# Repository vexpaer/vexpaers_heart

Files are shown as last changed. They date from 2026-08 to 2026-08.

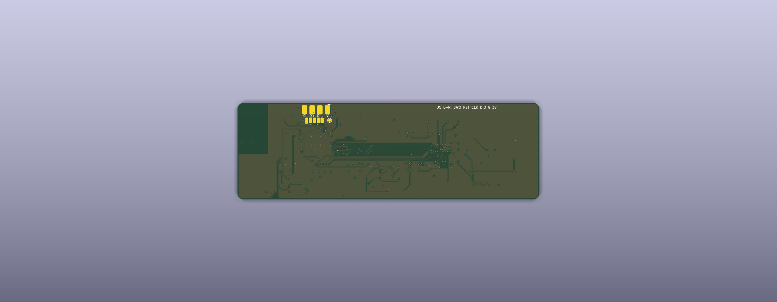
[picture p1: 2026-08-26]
hardware/heart_v2/docs/heart_v2_final_bottom_3d.png

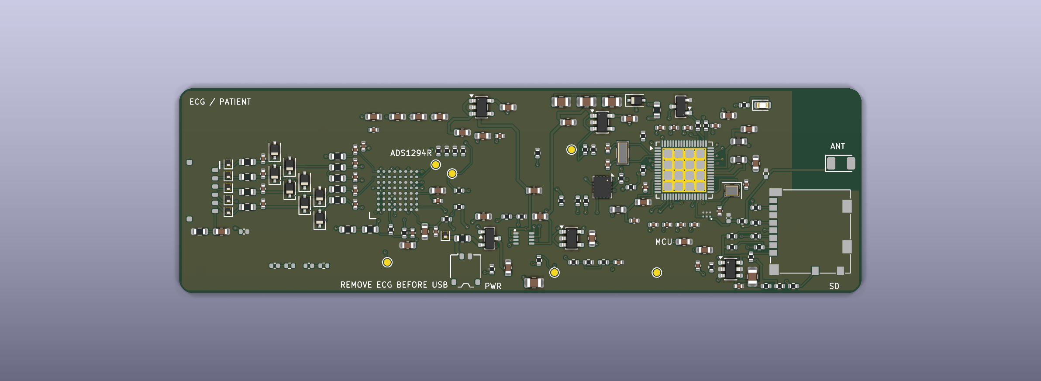
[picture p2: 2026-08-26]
hardware/heart_v2/docs/heart_v2_current_top_3d_close.png

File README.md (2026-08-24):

# vexpaer's heart — clean PCB rebuild

This branch resets the PCB layout workflow without losing the previous design.

- `Old/`: complete archived V1 design and production outputs.
- `reference/`: only the electrical/spec/library files needed for the rebuild.
- `hardware/heart_v2/`: clean workspace for the new PCB.
- `PCB_WORKFLOW.md`: the one document Codex should follow from setup to final manufacturing outputs.

The new PCB must be placement-first and human-routed. Do not use the archived PCB tracks or a global autorouter as the final layout.

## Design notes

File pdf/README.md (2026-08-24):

# PDF 审阅索引

这里的 PDF 由最终签核的 KiCad 文件生成，方便在不安装 KiCad 的设备上审阅。

- `holter_v1_schematic.pdf`：主板完整原理图；
- `holter_v1_pcb_layers.pdf`：主板四个铜层，每层一页并叠加板框；
- `holter_v1_assembly_top.pdf`：主板顶层装配图；
- `holter_v1_assembly_bottom.pdf`：主板底层装配图（已镜像为装配视角）；
- `usb_pogo_dock_schematic.pdf`：USB-Pogo 底座原理图；
- `usb_pogo_dock_pcb_layers.pdf`：底座两层铜层；
- `usb_pogo_dock_assembly_top.pdf`：底座顶层装配图；
- `usb_pogo_dock_assembly_bottom.pdf`：底座底层装配图。

PDF 用于人工审阅，不替代 `production/` 中的 Gerber、钻孔文件和签核报告。

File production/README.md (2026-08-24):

# 制造资料与下单说明

每个板卡子目录均包含 Gerber/Excellon、BOM、贴片坐标、钻孔报告、ERC/DRC
报告，以及可直接上传 PCB 厂商的 fabrication ZIP。厂商应以 Gerber 和钻孔文件
为制造依据；KiCad/PDF 用于工程复核。

## Holter 主板下单参数

- 首批数量：5；成品尺寸：100.0 mm × 30.0 mm；板厚：0.8 mm；
- 4 层：L1 元件/信号、L2 完整 GND、L3 电源/信号、L4 信号；
- 铜厚：各层 1 oz；表面处理：ENIG、无铅；
- 最小线宽/间距：0.10/0.10 mm；最小成品孔：0.20 mm；
- 全部 253 个过孔均为 0.45/0.20 mm 普通电镀通孔；没有盲孔、埋孔、
  微孔、盘中孔、填孔或盖孔要求；
- 阻焊覆盖普通过孔；颜色可选，但不得覆盖 J3/J5 的底层 Pogo/SWD ENIG
  接触面；
- 主要元器件仅顶层 SMT。J3、J5 是底层裸露接触焊盘，不是待贴装器件；
- DNP：C10、C26、C27、C65、C66、R18、R19；首板不要安装这些位置；
- 天线区域四层禁铺铜、禁放过孔；不得删除或缩小板文件中的 keepout。

### RF 与阻抗 EQ

RF 走线在顶层、宽 0.18 mm，参考 L2 GND。该线宽只有结合实际介质厚度与
介电常数后才可能构成 50 Ω。下单时要求厂商：

1. 按其 0.8 mm 四层量产层叠计算并确认顶层 0.18 mm 单端线的阻抗；
2. 目标 50 Ω，建议容差 ±10%；
3. 如果标准层叠无法满足，必须暂停 EQ 并反馈可用层叠/线宽，不得自行改线宽、
   板厚或天线 keepout 后直接生产。

RF π 网络的 C65/C66 首板保持 DNP、R51 安装 0 Ω。最终值只能在整机外壳、电池
和人体邻近条件下做 VNA 测量后冻结。

### USB 与 microSD 限制

- USB 仅按 USB 2.0 Full-Speed 12 Mbit/s 使用，不支持 High-Speed；当前走线不是
  紧密耦合的 90 Ω 差分对。首板必须做枚举、持续传输和供电切换测试；
- microSD 首板固件先用 4 MHz SPI 初始化和压力测试，通过后再提高；初始建议
  上限 12 MHz；
- 不得因厂商 EQ 任意更换 0.8 mm 层叠、改变 RF/USB 走线或移动器件。

## USB-Pogo 底座下单参数

- 首批数量：5；成品尺寸：42.0 mm × 24.0 mm；
- 2 层、1.6 mm、1 oz、ENIG、无铅；
- USB-C、ESD/保护器件和指示灯按 BOM/CPL 贴装；
- Pogo 弹簧针与机械定位件由夹具结构决定，按装配图手工安装；
- 与主板接触顺序固定为 `VBUS / D- / D+ / GND`，不得镜像或调换。

## 安全标识与首板验证

主板和夹具上的 `DISCONNECT ELECTRODES BEFORE USB` / 互锁提示不得删除。
本设计没有患者侧 USB 隔离，连接人体电极时严禁连接 USB/Pogo；USB 导出或刷机
前必须先拔下整条电极线缆。

这是一套研究原型，不是医疗器械。任何人体连接之前，必须先在 ECG 模拟器和
患者等效假负载上验证输入漏电/偏置、RLD 稳定性、噪声、ESD 恢复和故障状态；
同时完成 RF、USB、microSD、电源温升、反向电流、电池极性及机械互锁验证。

详细证据和仍需实测的项目见 `docs/HARDWARE_AUDIT.md`。

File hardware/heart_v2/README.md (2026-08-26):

# heart_v2

Heart V2 Rev A is a clean, from-schematic PCB rebuild for the Holter research
prototype.  The layout is frozen as a four-layer, 0.8 mm, 100 mm x 32 mm board.
The extra 2 mm is a user-authorized service strip for separate bottom-side USB
and SWD pogo rows.

The placement and routing are deliberately scripted and reproducible.  They do
not read an archived PCB, reuse `Old/` copper, invoke Freerouting, or call a
global autorouter.

## Release status

- ERC: 0 errors, 0 warnings
- DRC: 0 violations, 0 unconnected pads, 0 footprint errors
- Schematic/PCB electrical parity: clean
- Fabrication, assembly and review outputs: `production/`
- Layout audit and first-board checks: `docs/AUDIT.md`

This is a research prototype, not a medical device.  It has no patient-side USB
isolation or defibrillation protection.  Disconnect every electrode before
connecting USB, exactly as the board silkscreen states.

## Source and regeneration

- `heart_v2.kicad_sch`, `heart_v2.kicad_pcb`, `heart_v2.kicad_pro`: KiCad 10 source
- `scripts/place_components.py`: deterministic functional placement and outline
- `scripts/route_board.py`: deterministic human-style routing, zones and stitching
- `scripts/export_release.sh`: final checks and manufacturing export
- `libraries/`: project symbols and footprints

Run the placement and routing scripts with a Python environment that provides
KiCad 10 `pcbnew`, then run the release exporter:

```bash
python3 scripts/place_components.py
python3 scripts/route_board.py
bash scripts/export_release.sh
```

Do not regenerate this board from `Old/`; that directory remains archival only.

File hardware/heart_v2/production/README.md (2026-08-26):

# Heart V2 Rev A production package

Fabrication target: four layers, 0.8 mm, 100 x 32 mm, ENIG.  Confirm the exact
0.8 mm stackup and the 0.24 mm 50-ohm RF geometry with the selected board house
before ordering.

## Files

- `heart_v2_fab_revA.zip`: Gerber X2/job, PTH/NPTH drill and IPC-D-356 data.
- `heart_v2_release_revA.zip`: complete source, checks, fabrication and assembly
  deliverables.
- `heart_v2_bom.csv`: assembly BOM with DNP parts excluded.
- `heart_v2_bom_all.csv`: engineering BOM including DNP parts.
- `heart_v2_cpl.csv`: both-side metric placement file, DNP excluded.
- `docs/heart_v2_assembly_top.pdf`: 1:1 top assembly drawing.
- `docs/heart_v2_assembly_bottom.pdf`: 1:1 mirrored bottom assembly drawing.
- `docs/heart_v2_copper_layers.pdf`: four-page 1:1 copper review drawing.
- `docs/heart_v2_schematic.pdf`: schematic review PDF.
- `../docs/jlcpcb_pcba_order_guide.html`: detailed Chinese JLCPCB PCB+SMT ordering
  and first-board bring-up guide (open locally in a browser).

Gerber, drill and CPL outputs share the physical lower-left board corner as
their origin.  CPL positions are all positive.  Verify bottom-side rotation and
the rendered placement preview in the assembler portal before approval.

J3/J5 USB/SWD pogo contacts and TP1-TP6 test pads are bare board-contact/test
structures, not SMT parts, so they are intentionally omitted from the BOM/CPL
matching list.  The assembled board still contains their copper pads.

The board is a non-isolated research prototype.  Disconnect electrodes before
USB, and validate with an ECG simulator/patient-equivalent load before any human
connection.

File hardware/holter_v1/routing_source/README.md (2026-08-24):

# Routing source

`holter_v1-freerouted-input.kicad_pcb` is the frozen Freerouting intermediate
used by `tools/finish_main_routes.py`. It is committed only to make the final
manual routing stage reproducible.

Do **not** send this intermediate board to a manufacturer. It does not contain
the final PA10 microSD-CS/SD-clock completion and its imported layer-changing
drills may still be labelled as buried vias. The signed-off fabrication source
is `../holter_v1.kicad_pcb`; the finishing script converts every final drill to
a 0.45/0.20 mm ordinary plated through-via before saving.

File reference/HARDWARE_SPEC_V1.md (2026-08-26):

# Holter V1 Hardware Specification

**项目名称**：Holter V1<br>
**用途**：研究/个人工程原型；连续 ECG + 运动数据记录<br>
**硬件 CAD**：KiCad<br>
**目标生产方式**：PCB 打样 + SMT 贴片，拿到板后通过 SWD/USB 烧录固件<br>
**版本**：V1.0<br>
**状态**：规格冻结；Heart V2 Rev A 制造发布候选已完成 ERC/DRC 签核（2026-08-26）

> 2026-08-23 实施修订：原规格中的 `STM32WB55CGU6 / UFQFPN48` 无法同时提供两组完整、独立的 SPI 引脚。V1 已改为 `STM32WB55RGV6 / VFQFPN68`，ADS1294R 使用 SPI1，microSD 使用 SPI2。本修订属于修复引脚资源冲突，不改变 1 MB Flash、BLE 或 USB FS 功能目标。

> 2026-08-26 机械实施修订：经用户授权，最终 PCB 在原 100 × 30 mm 上限基础上仅向北侧增加 2 mm 服务触点带，成品外形为 **100 × 32 mm**。新增面积用于分离 USB/SWD Pogo 排，不改变 ECG、microSD 或天线端的功能分区；外壳和夹具以最终板框为准。

---

## 1. V1 核心目标

设计一块可放入薄型金属盒中的低功耗可穿戴 ECG 记录主板：

- PCB 最终外形：**32 mm × 100 mm**（含 2 mm 服务触点带）
- PCB 建议厚度：**0.8 mm，4 层**
- 主板总高度目标：**≤ 3 mm**（不计外部电池、导联线、电极）
- 外壳内部高度目标：约 **5 mm**
- 尽量采用**单面贴装**：所有主要器件放在 PCB 同一面，背面尽量只保留测试点、Pogo 接触区和必要铜面
- 5 个体表电极，一根总线从设备引出后分成 5 根电极线
- 连续记录 ECG 和 IMU
- 本地 microSD 存储
- BLE 用于配置、状态、时间同步和短时实时预览
- USB 2.0 Full-Speed 通过 4 个 Pogo 触点进行数据导出和正常固件升级
- 电池可手动更换，主板**不包含充电电路**

> 本项目是研究/工程原型，不作为医疗诊断设备使用。

---

## 2. 已冻结的核心器件

### 2.1 ECG AFE

**TI ADS1294R**

要求：

- 4 通道
- 24-bit 同步 ADC
- SPI 接口
- 默认采样率：**500 SPS**
- CH1~CH3 用于 ECG
- CH4 预留为备用生物电通道
- 使用 ADS1294R 内置：
  - RLD（Right Leg Drive）
  - Lead-off detection
  - Wilson Central Terminal（WCT）
  - 内部参考/时钟方案按 TI datasheet 与官方参考设计实现
- V1 暂不要求启用呼吸阻抗功能，但不得破坏以后启用的可能性

封装优先：
- **NFBGA 8 mm × 8 mm**，以降低面积和高度
- 如果 SMT 厂 BGA 能力/成本不合适，再评估其他可采购封装；任何封装变更必须记录在设计说明中

### 2.2 主控 MCU

**ST STM32WB55RGV6**

要求：

- VFQFPN68，约 **8 × 8 × 1 mm**
- BLE
- USB 2.0 Full-Speed Device
- 1 MB Flash
- MCU 同时负责：
  - ADS1294R SPI 采集
  - microSD SPI 写入
  - IMU 采集
  - BLE
  - USB 数据导出
  - RTC/时间管理
  - 电池电压检测
  - Lead-off 状态处理
- 固定总线分配：
  - SPI1：ADS1294R（PA5/PA6/PA7，PA4 片选）
  - SPI2：microSD（PB13/PB14/PB15；PA10 作为软件控制片选）
  - I²C1：BMI270（PB8/PB9）

### 2.3 IMU

**Bosch BMI270**

要求：

- 6 轴 IMU：3 轴加速度 + 3 轴陀螺仪
- I²C 或 SPI；V1 优先 I²C，以节省 SPI 片选和布线复杂度
- 默认记录频率：**50 Hz**
- 后续固件允许降到 25 Hz
- 用途：活动、姿态变化、运动伪迹辅助判断

### 2.4 存储

**32 GB microSD / microSDHC**

要求：

- **只使用 microSD，不预留 SPI NAND**
- MCU 通过 **SPI 模式**访问 microSD
- 采用超薄、水平侧插卡座
- microSD 与 PCB **平行**
- 卡从外壳侧面/端部沿 PCB 平面滑入
- 卡座总高度优先 **≤ 1.5 mm**
- 优先 push-push 或可靠 push-pull 结构
- 卡槽建议布置在 PCB 的一个短边，外壳对应位置开 microSD 插入口
- 插卡状态检测如卡座支持则接入 MCU

建议文件系统：
- 32 GB：FAT32
- 固件必须使用顺序追加写入，避免大量随机写
- 建议使用 RAM buffer 后按较大 block 写入 microSD，降低功耗和掉电损坏风险

---

## 3. 电极与 ECG 通道定义

### 3.1 五电极

一根总导联线从主机引出，再分成：

1. **RA**
2. **LA**
3. **LL**
4. **RL**
5. **V5**

长期佩戴时可使用躯干化的 Holter 电极布置，而不是四肢末端位置。

建议人体位置：

- RA：右上胸
- LA：左上胸
- LL：左下胸/左下躯干
- RL：右下胸/右下躯干
- V5：左侧 V5 区域（与 V4 同水平、接近左前腋线）

注意：这种长期佩戴布置属于 Holter/监护式躯干电极布置，所得肢体导联形态不能假定与标准静息 12 导联四肢末端放置完全一致。

### 3.2 采集通道

目标：

- **CH1：Lead I = LA - RA**
- **CH2：Lead II = LL - RA**
- **CH3：V5 - WCT**
- **CH4：备用**

其中：

- WCT 由 RA、LA、LL 形成 Wilson Central Terminal
- CH3 必须依据 ADS1294R 的 WCT 推荐电路/寄存器实现，不要把 V5 简单接成 V5-RA

软件可由 CH1、CH2 计算：

- Lead III = Lead II - Lead I
- aVR = -(Lead I + Lead II) / 2
- aVL = Lead I - Lead II / 2
- aVF = Lead II - Lead I / 2

因此 V1 可输出：

- I
- II
- III
- aVR
- aVL
- aVF
- V5

其中前 6 个肢体方向只有 2 个独立自由度；V5 是额外真实胸导联信息。

---

## 4. ECG 输入与人体安全要求

这一部分优先级高于尺寸和 BOM 成本。

### 4.1 原则

- 输入保护、RLD、RC/EMI 网络优先参考 TI ADS129x 官方 ECG 参考设计和 datasheet
- 禁止由 Agent 自行“猜”患者输入保护电路
- 输入保护器件必须关注：
  - 漏电流
  - 输入偏置影响
  - ESD
  - RF/EMI
  - 限流
  - 电极断开状态
- 输入走线尽可能短、对称，远离：
  - USB
  - microSD 时钟
  - MCU 高频时钟
  - BLE RF
  - DC/DC 开关节点

### 4.2 USB 使用安全

**佩戴电极时，不允许连接电脑 USB/Pogo。**

V1 没有医疗级 USB 隔离，因此：

- USB 数据导出/刷机前先拔掉 5 电极导联总线
- Pogo VBUS 不得给锂电池充电
- USB 供电路径与电池路径需要避免反灌
- PCB 上明确丝印/说明：
  - `DISCONNECT ELECTRODES BEFORE USB`

### 4.3 RLD

- RL 电极作为 RLD/偏置驱动电极使用
- RLD 回路必须按照 ADS1294R datasheet 与官方 ECG 参考设计实现
- RLD 稳定性网络必须计算并在原理图中标注设计依据

---

## 5. 电源架构

### 5.1 电池

- 单节 **3.7 V 1000 mAh LiPo**
- 可拆卸
- 用户准备两块电池轮换
- 目标换电周期：约每 **12 小时**
- 主板**不集成充电器**

要求使用带自身保护的电池包，主板额外提供：

- 反接/反灌保护
- 过流保护或合适的保险/限流方案
- 欠压检测
- 电池电压 ADC 采样

### 5.2 电池连接器

- 2-pin
- 低高度
- 侧插
- 带防呆/锁定优先
- 高度目标 ≤ 2 mm 左右
- 最终型号根据 SMT 厂可采购库存决定，但不得使用明显超过 3 mm 的高连接器

### 5.3 电源轨

设计目标：

- 模拟和数字区域分区供电、布局隔离
- 不为了省一个 LDO 而让 microSD/MCU 的数字噪声直接污染 ECG AFE
- 优先评估：
  - `3.0 V_A`：ADS1294R 模拟
  - `3.0 V_D`：STM32WB / ADS1294R DVDD / IMU / microSD
  - `3.3 V_USB`：仅由 USB VBUS 产生，专供 STM32 VDDUSB
- 低噪声 LDO 优先
- 如果必须使用开关电源，开关节点必须远离 AFE，并经过低噪声后级处理；V1 尽量避免不必要的 DC/DC

电池最低工作电压、LDO dropout、STM32 USB VDDUSB 要结合 datasheet 重新核算后冻结。

---

## 6. 换电与 RTC

V1 允许换电时产生几秒钟 ECG 中断，不做真正的无缝热插拔。

要求：

- STM32 RTC 用于绝对时间
- 增加低高度 RTC/backup hold-up 电容
- 目标：拔电池后至少保持 RTC/关键状态 **≥ 60 秒**
- 换电后：
  - 自动重新初始化 ADS1294R、IMU、microSD
  - 建立新 recording segment
  - 在日志中写入 battery swap / reboot 事件
- 如果 RTC hold-up 失效：
  - BLE 或 USB 重新同步时间
  - 禁止悄悄生成错误绝对时间

---

## 7. BLE

用途限定为：

- 配置
- 时间同步
- 电池状态
- microSD 容量
- 电极 lead-off 状态
- 开始/停止记录
- 短时间实时 ECG 预览
- 固件状态/版本信息

BLE **不作为每天数百 MB 数据的主要导出通道**。

### 金属外壳注意

铁盒会显著衰减 2.4 GHz BLE。

PCB 必须：

- 给天线留完整 RF keepout
- 天线尽量位于 PCB 边缘
- 天线位置对应外壳塑料窗口/开口，或接受“开盖后使用 BLE”
- 不允许把 PCB 天线完全压在连续金属盒壁下仍假定 BLE 正常

V1 建议预留匹配网络，使用低高度 2.4 GHz 芯片天线或经验证的 PCB 天线方案。

---

## 8. USB + Pogo 数据接口

### 8.1 外露触点

主机不安装 USB-C 母座。

PCB 上留 4 个镀金平面触点：

1. VBUS
2. D-
3. D+
4. GND

由外部 Pogo Pin 底座连接：

`Holter PCB pads -> Pogo fixture -> USB-C cable -> PC`

建议：

- 触点采用 ENIG
- 2.0~2.54 mm 级别间距，优先便于手工夹具制作
- 触点周围留机械定位空间
- D+/D- 作为 USB 差分对布线
- 加低电容 USB ESD 保护
- VBUS 仅用于 USB 检测/受控供电，不用于电池充电

### 8.2 USB 功能

STM32WB55 使用 USB 2.0 Full-Speed Device。

固件目标支持：

- DFU/Bootloader 固件升级
- 数据导出
- 优先考虑 USB Mass Storage 或自定义 bulk protocol

重要性能预期：

- USB Full-Speed 理论总线速率 12 Mbit/s
- 实际文件导出不会达到 10 MB/s
- 预期有效吞吐约数百 KB/s ~ 1 MB/s 级，需实测优化
- 约 450~500 MB/天的数据，Pogo USB 导出大约是**数分钟到十几分钟级**

如希望几十秒导完，可以直接拔出 microSD 用高速读卡器。

---

## 9. SWD 调试/救砖接口

除 USB Pogo 外，必须保留独立隐藏 SWD 测试点。

至少：

- 3V3
- GND
- SWDIO
- SWCLK
- NRST

要求：

- 不焊排针
- 仅做金属测试 pad
- 可用 Pogo/夹具连接 ST-LINK
- 保证即使 USB Bootloader 损坏仍可重新烧录
- 在 PCB 丝印/装配图中明确 pin definition

---

## 10. ECG 导联总接口

使用**一个低高度多芯接口**连接主机和五电极分线。

目标：

- 5-position 锁定连接器
- RA / LA / LL / RL / V5
- 一根主线从设备出去后，再在远端分成 5 根电极线
- 接口优先放在靠近 ADS1294R 的 PCB 短边
- 连接器高度尽量 ≤ 2 mm
- 具有防呆
- 具备足够插拔寿命

V1 固定使用 6-position 低高度防呆连接器；第 6 pin 定义为：
- spare / shield / cable detect
且不得随意连接人体参考。

---

## 11. PCB 机械与布局

### 11.1 外形

- 最终：32 × 100 mm（含 2 mm 服务触点带）
- 优先做成长条圆角矩形
- PCB：4 层
- 厚度：0.8 mm
- 表面处理：ENIG 优先
- SMT：优先单面装配

### 11.2 推荐功能分区

从一端到另一端：

`ECG connector -> patient protection -> ADS1294R analog zone -> STM32WB digital zone -> microSD / USB zone`

IMU：
- 放在机械上相对稳定的位置
- 避免紧贴 Pogo 接触点和容易被手指按压变形的位置

RF：
- 放在 PCB 边缘
- 远离 ADS1294R 输入端
- 保留天线 keepout

### 11.3 microSD

microSD 放在远离 ECG 模拟输入的一端。

方向：

- 卡片平面与 PCB 平行
- 沿 PCB 长度方向或短边方向水平滑入
- 外壳开槽只需暴露卡的插拔边缘
- 禁止使用垂直插卡座

### 11.4 地与分区

- 使用连续、低阻抗 ground plane
- 通过器件布局实现 analog/digital/RF 分区
- 不要随意把地平面切成多个导致回流绕路的孤立区域
- ECG 输入下方/附近的回流路径、guard、shield 策略必须依据 ADS1294R 参考设计评估

---

## 12. 数据率与存储预算

### ECG

3 个实际 ECG 通道：

- 500 samples/s
- 24 bit = 3 bytes/sample

纯 ECG：

`3 × 500 × 3 × 86400 = 388,800,000 bytes/day`

约 **389 MB/day**（十进制）。

### IMU

若 6 轴全部保存为 16-bit：

- 12 bytes/sample
- 50 Hz

约：

`12 × 50 × 86400 = 51,840,000 bytes/day`

约 **52 MB/day**。

### 总预算

加上：

- block timestamp
- sample counter
- lead-off / event log
- header
- CRC
- 文件系统开销

V1 按 **450~500 MB/day** 规划。

32 GB microSD：

- 理论可保存 60 天以上
- 工程上按**至少 50 天连续数据容量**设计即可

不要给每个 ECG sample 写完整 64-bit timestamp；采用 block timestamp + sample index，降低冗余。

---

## 13. 数据文件原则

固件阶段再详细定义，但硬件/软件接口需预留以下字段：

文件头：

- magic
- file format version
- device serial
- firmware version
- recording start UTC/local time
- ECG sampling rate
- enabled channels
- gain
- electrode configuration
- IMU rate
- calibration information

数据 block：

- block sequence
- block timestamp
- ECG samples CH1/CH2/CH3
- IMU samples
- status / lead-off flags
- CRC

原则：

- microSD 必须保存尽量接近 ADC 原始值的数据
- 不允许只保存经过显示滤波后的 ECG
- 软件滤波可在导出后完成
- 掉电后应尽可能恢复到最后一个完整 block

---

## 14. V1 生产输出要求

KiCad 工程完成后，必须产生：

### 工程文件

- `.kicad_pro`
- `.kicad_sch`
- `.kicad_pcb`

### 检查

- ERC 无未解释严重错误
- DRC 无未解释严重错误
- 所有未连接 pin 有明确理由
- polarity/orientation 检查
- BGA/QFN exposed pad 检查
- microSD 卡插入方向检查
- 天线 keepout 检查
- Pogo pinout 二次检查
- SWD pinout 二次检查

### 生产文件

- Gerber
- Drill
- BOM
- Pick & Place / CPL
- 装配图
- 原理图 PDF
- PCB 3D 截图
- `production.zip`

BOM 应包含：

- Manufacturer
- Manufacturer Part Number
- Value
- Package
- Quantity
- Reference
- 可选的 JLC/LCSC part number

---

## 15. Codex 执行要求

Codex 接到本文件后按以下阶段工作。

### Phase 1 — 器件与参考设计核验

1. 阅读最新版：
   - ADS1294R datasheet
   - ADS129x ECG 官方参考设计/应用资料
   - STM32WB55RG datasheet
   - STM32WB hardware design guidelines
   - BMI270 datasheet
2. 核验所有电压、USB pin、RF、SPI、WCT、RLD、lead-off 配置。
3. 为所有关键器件确认 KiCad symbol/footprint。
4. 建立 `DECISIONS.md`，记录所有实际料号和设计选择。
5. **有任何 datasheet 冲突时，以 datasheet 为准，不照抄本规格里的假设值。**

### Phase 2 — 原理图

模块化建立：

- BATTERY / POWER
- STM32WB55
- BLE RF
- USB POGO
- SWD
- ADS1294R POWER/REFERENCE
- ECG INPUT PROTECTION
- RLD/WCT
- IMU
- MICROSD
- CONNECTORS

完成 ERC 后再进入 PCB。

### Phase 3 — PCB

1. 建立 32 × 100 mm 最终 board outline（含 2 mm 服务触点带）。
2. 先完成机械关键项：
   - ECG connector
   - microSD slot
   - Pogo pads
   - antenna/keepout
3. 再放 ADS1294R 和 patient protection。
4. 再放 MCU/IMU/SD/电源。
5. 优先单面 SMT。
6. 完成 4-layer stackup。
7. 做 DRC。
8. 检查器件实际高度，输出 `HEIGHT_BUDGET.md`。

### Phase 4 — 对抗式审查

至少进行一轮独立审查，重点寻找：

- ECG 输入错误
- WCT/RLD 接法错误
- 电源域错误
- USB VBUS/反灌
- microSD 热插拔/电源问题
- RF 天线被金属外壳屏蔽
- SPI pin 冲突
- SWD 被占用
- 未处理 BOOT/NRST
- 换电 RTC 丢失
- ESD 漏电污染 ECG
- 0402/0201 可制造性
- BGA escape routing
- 生产厂无法贴装的料号
- 高度超过目标

### Phase 5 — 生产包

最终目录建议：

```text
holter/
├── HARDWARE_SPEC_V1.md
├── DECISIONS.md
├── hardware/
│   ├── holter.kicad_pro
│   ├── holter.kicad_sch
│   └── holter.kicad_pcb
├── datasheets/
├── docs/
│   ├── schematic.pdf
│   ├── assembly.pdf
│   ├── HEIGHT_BUDGET.md
│   └── bringup_checklist.md
├── production/
│   ├── gerber/
│   ├── drill/
│   ├── bom.csv
│   ├── cpl.csv
│   └── production.zip
└── firmware/
```

---

## 16. 第一块板上电原则

SMT 板回来后不要直接贴到人体。

Bring-up 顺序：

1. 目检和显微检查
2. 不装电池，检查各电源 rail 对地阻抗
3. 实验室限流电源供电
4. 测试 3.0V/各 rail
5. SWD 识别 STM32WB
6. 烧最小测试固件
7. 测试 USB Pogo
8. 测试 BLE
9. 测试 microSD
10. 测试 IMU
11. ADS1294R internal test signal
12. 外部函数发生器/ECG simulator 输入
13. 检查 RLD/WCT/lead-off
14. 检查噪声、工频、基线漂移
15. **确认 USB 完全断开后**，才进入人体电极实验

V1 不做医疗认证，不得把“能看到 ECG”视为已经满足临床安全或诊断要求。

---

## 17. 当前冻结决策摘要

| 项目 | V1 |
|---|---|
| MCU | STM32WB55RGV6 / VFQFPN68 |
| ECG AFE | ADS1294R |
| ECG 实际通道 | 3 |
| 备用通道 | 1 |
| 电极 | RA / LA / LL / RL / V5 |
| ECG 采样 | 500 SPS / 24 bit |
| IMU | BMI270 / 50 Hz |
| 存储 | 32 GB microSD |
| microSD 方向 | 与 PCB 平行、水平侧插 |
| SPI NAND | 不使用、不预留 |
| BLE | 配置/预览 |
| 高速导出 | USB FS via 4 Pogo pads |
| Pogo | VBUS / D- / D+ / GND |
| 调试 | 独立隐藏 SWD pads |
| 电池 | 3.7V 1000mAh 可更换 |
| 充电 | 主板无充电功能 |
| 导联接口 | Molex Pico-EZmate 6-pin；RA/LA/LL/RL/V5 + shield/detect |
| PCB | 32×100 mm，0.8 mm 4-layer |
| 总板高目标 | ≤3 mm |
| 外壳内部高度目标 | 约5 mm |
| 数据预算 | 约450~500 MB/day |
| USB 与人体 | 禁止同时连接 |
| 制造目标 | JLCPCB Standard PCBA；首批 5 套；ENIG；单面 SMT |
| 外壳 | 金属主体 + 天线端塑料 RF 窗/端盖，闭盖 BLE |
| 人机界面 | 无按键、自动记录、单颗状态 LED |
| USB 夹具 | 独立 USB-C-to-Pogo 小板；与 ECG 插头机械互锁 |

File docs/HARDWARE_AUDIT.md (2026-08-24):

# Holter V1 hardware release audit

Generated 2026-08-24 from the signed-off KiCad board.

## Release gates

- Main schematic: ERC 0 errors / 0 warnings.
- Main PCB: DRC 0 violations, 0 unconnected pads, 0 footprint errors.
- Vias: 253; all plated through, F.Cu–B.Cu, 0.45/0.20 mm; no blind, buried, or microvias.
- BOM: 159 source rows, 152 fitted and 7 DNP; every fitted row has a manufacturer part number.
- PCB footprint values match the BOM source; the pin/net audit has no electrical mismatches.
- Expected mechanical-only extra pads: J1-MP, J2-MP.

## Physical and layout checks

- Nominal outline: 100.00 × 30.00 mm (Edge.Cuts bounding box including stroke: 100.05 × 30.05 mm); board thickness 0.8 mm, four copper layers.
- Placement: 165 footprints on top; bottom only J3, J5; every footprint has a courtyard.
- In1.Cu has no signal tracks and contains the solid GND plane (normal pad/via antipads still apply).
- Antenna rule-area keepout is present on all four copper layers and measures 5.1 × 10.0 mm; pours and vias are forbidden there while the antenna feed is allowed.
- RF, HSE, LSE, and STM32 SMPS critical nets are front-layer-only and via-free.

## Routed-net measurements

| Net | Copper length | Vias | Layers | Widths |
|---|---:|---:|---|---|
| `USB_DM` | 39.69 mm | 3 | B.Cu, F.Cu, In2.Cu | 0.15 mm |
| `USB_DM_POGO` | 11.02 mm | 1 | B.Cu, F.Cu | 0.15 mm |
| `USB_DP` | 47.67 mm | 6 | B.Cu, F.Cu, In2.Cu | 0.15 mm |
| `USB_DP_POGO` | 11.24 mm | 2 | B.Cu, F.Cu, In2.Cu | 0.15 mm |
| `SD_SCK_MCU` | 33.18 mm | 3 | B.Cu, F.Cu, In2.Cu | 0.10 mm |
| `SD_MISO_MCU` | 36.64 mm | 3 | B.Cu, F.Cu, In2.Cu | 0.10 mm |
| `SD_MOSI_MCU` | 48.40 mm | 4 | F.Cu, In2.Cu | 0.15 mm |
| `SD_CS_MCU` | 38.01 mm | 5 | B.Cu, F.Cu, In2.Cu | 0.10 mm, 0.15 mm |
| `RF_MCU` | 1.91 mm | 0 | F.Cu | 0.10 mm, 0.18 mm |
| `RF_FILTER_OUT` | 52.91 mm | 0 | F.Cu | 0.18 mm |
| `RF_ANT_FEED` | 4.24 mm | 0 | F.Cu | 0.18 mm |
| `HSE_IN` | 12.29 mm | 0 | F.Cu | 0.10 mm, 0.12 mm |
| `HSE_OUT` | 5.67 mm | 0 | F.Cu | 0.10 mm, 0.12 mm |
| `LSE_IN` | 9.60 mm | 0 | F.Cu | 0.10 mm, 0.12 mm |
| `LSE_OUT` | 8.09 mm | 0 | F.Cu | 0.12 mm |
| `SMPS_IN` | 4.31 mm | 0 | F.Cu | 0.10 mm, 0.25 mm |
| `SMPS_SW` | 2.60 mm | 0 | F.Cu | 0.10 mm, 0.25 mm |
| `SMPS_FB` | 5.39 mm | 0 | F.Cu | 0.10 mm, 0.20 mm, 0.25 mm |

## Interface assessment

- USB routed endpoint paths (excluding ESD branches and the two 22 Ω resistor bodies): D− 48.39 mm, D+ 56.91 mm; length difference 8.52 mm. FR-4 propagation gives an estimated 50–60 ps skew. This release is for USB 2.0 Full-Speed (12 Mbit/s) only, not High-Speed; verify the selected stackup and USB behavior on the first article.
- The USB routes are not a tightly coupled controlled-impedance pair and use several vias. This is accepted for the Full-Speed prototype only and remains a first-article validation item.
- microSD MCU-side routed lengths are SCK 33.18 mm, MISO 36.64 mm, MOSI 48.40 mm, and CS 38.01 mm. Start first-board firmware at 4 MHz SPI and increase only after validation; 12 MHz is the initial recommended ceiling.
- The 2.4 GHz feed is top-layer and via-free over the In1 ground reference. Its 0.18 mm line width is not a universal 50 Ω value: the PCB vendor must calculate/confirm impedance against the actual 0.8 mm four-layer stackup, and the assembled unit requires VNA/closed-enclosure matching validation.

## ECG/RLD/WCT review

- CH1 is LA−RA, CH2 is LL−RA, and CH3 is V5−WCT; CH4 is reserved with test points. The PCB pin map matches the schematic audit CSV.
- RA/LA/LL/V5 each use two 47.5 kΩ series resistors with C0G filtering and low-leakage clamps; RLD uses 2 × 162 kΩ series limiting.
- RLDOUT/RLDINV compensation is 1 MΩ in parallel with 1.5 nF; WCT is routed to CH3N with 100 pF to ground.
- These checks establish schematic/PCB consistency only. Before any human connection, validate on an ECG simulator and patient-equivalent load: input leakage/bias, RLD stability, recovery after ESD, noise, lead-off behavior, and all relevant safety limits.

## First-article items that remain open

- RF return loss, π-network values, BLE range in the final enclosure and near the body.
- USB Full-Speed eye/function, microSD write peaks and SPI margin, RTC hold-up time, regulator temperatures, and power-path reverse-current behavior.
- Battery connector polarity, protected-pack thresholds, enclosure tolerances, Pogo alignment, and mechanical USB/electrode interlock.
- The design is a research prototype, not an IEC 60601-qualified medical device and not suitable for diagnosis or clinical decisions.

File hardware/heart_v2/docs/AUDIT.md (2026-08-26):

# Heart V2 Rev A PCB Audit

**Layout freeze:** 2026-08-26  
**Status:** manufacturing release candidate; first-board electrical, RF and
patient-equivalent-load validation is still required.

## Sign-off

| Check | Result | Evidence |
|---|---:|---|
| Schematic ERC | 0 errors, 0 warnings | `erc_final.rpt` |
| PCB DRC | 0 violations | `drc_final.rpt` |
| Connectivity | 0 unconnected pads | `drc_final.rpt` |
| Footprint errors | 0 | `drc_final.rpt` |
| Schematic/PCB electrical parity | clean | `kicad-tool pcb validate` |

The parity tool also reports 149 `footprint_symbol_field_mismatch` warnings.
They are documentation-field differences (`Description`, `Datasheet`, and
`Manufacturer`) between schematic symbols and instantiated PCB footprints;
they are not reference, value, footprint assignment, pad or net mismatches.

## Construction

- Board: 100.0 mm x 32.0 mm, 2.0 mm corner radius, 0.8 mm finished thickness.
- Stack: L1 components/signals, L2 GND reference, L3 power/signals, L4 signals.
- 167 footprints, 575 pads, 1,109 track segments and 227 through vias.
- Track widths used: 0.15 to 0.45 mm; minimum finished drill: 0.20 mm.
- 24 deliberate GND stitching vias supplement device escape/return vias.
- Top-side component density: 29.90%; bottom side is limited to three service
  footprints/contact structures (2.31%).
- Antenna keepout removes copper, tracks and vias on all four layers.
- Fabrication/pick-place datum is the physical lower-left corner.  CPL extents
  are X=3.0..97.0 mm and Y=1.0..29.5 mm, with no negative coordinates.
- J3/J5 USB/SWD pogo contacts and TP1-TP6 test pads are bare PCB contact/test
  structures; they are explicitly excluded from BOM/CPL placement matching,
  while remaining in the PCB copper and assembly drawings.

The board was rebuilt from the reference schematic and libraries.  No tracks,
vias or placement from `Old/` were reused, and no global autorouter was used.

## Routing review

Placement reads left-to-right as patient connector/protection -> ADS1294R ->
power/IMU -> STM32WB55 -> microSD/RF.  Patient input chains are aligned,
decouplers face their supply pins, MCU/ADS escapes use regular lanes, and the
long digital buses remain parallel instead of wandering between components.

L2 is a continuous GND pour except for two short, deliberate `/3V0_D` bridges:

1. a local bridge beneath U3 joining VDD drops separated by the ADS buses;
2. the J5 3 V reference feed around the USB/SWD service area.

Both alternatives were trial-routed on L3/L4 and rejected because the existing
continuous ADS/USB buses force crossings or a long perimeter detour.  The two
short L2 slots are away from RF and ECG entry traces and are bracketed by nearby
GND stitching vias.  They are controlled layout exceptions, not hidden DRC
waivers.

## Critical-net measurements

Lengths below are routed copper centerline lengths; vias are counted per KiCad
net.  Series components split some physical interfaces into multiple net names.

| Interface/net | Length | Vias | Layers/assessment |
|---|---:|---:|---|
| RF MCU -> filter (`RF_MCU`) | 3.989 mm | 0 | F.Cu |
| RF filter/match (`RF_FILTER_OUT`) | 5.456 mm | 0 | F.Cu |
| RF match -> antenna (`RF_ANT_FEED`) | 18.052 mm | 0 | F.Cu |
| USB MCU-side D- (`USB_DM`) | 2.765 mm | 0 | F.Cu |
| USB MCU-side D+ (`USB_DP`) | 2.268 mm | 0 | F.Cu |
| USB complete D- path | 16.450 mm | 2 | Pogo/ESD side plus MCU side |
| USB complete D+ path | 8.585 mm | 1 | Pogo/ESD side plus MCU side |
| SD SCK, MCU side | 14.556 mm | 2 | F.Cu/In2.Cu |
| SD MOSI, MCU side | 18.733 mm | 2 | F.Cu/B.Cu |
| SD MISO, MCU side | 13.137 mm | 2 | F.Cu/In2.Cu |
| SD CS, MCU side | 26.638 mm | 2 | F.Cu/B.Cu |
| ECG RA/LA/LL/V5 connector entry | 3.983..4.936 mm | 0 | F.Cu, aligned protection chains |
| RLD-to-RL driven path (`RL_ELEC`) | 24.224 mm | 3 | Not a measurement input pair |

The USB device-side pair is matched to 0.497 mm and is via-free.  The Pogo side
is asymmetric because the fixed `VBUS / D- / D+ / GND` contact order and the
three-pad shunt ESD footprint do not permit a natural mirrored path.  No
serpentine was added merely to equalize a 12 Mbit/s USB Full-Speed interface;
enumeration and sustained-transfer testing remain mandatory on the fixture.

The complete RF chain is 27.497 mm, top-layer and via-free over the L2 reference.
The 0.24 mm RF width must be confirmed against the exact fab stackup, and the
DNP matching capacitors must be tuned in the final enclosure.

## Assembly notes

- DNP: C10, C26, C27, C65, C66, R18 and R19.
- USB Pogo order: `VBUS / D- / D+ / GND`.
- Bottom J5 legend gives the physical left-to-right debug order.
- Do not connect USB while electrodes are attached.
- `heart_v2_bom.csv` and `heart_v2_cpl.csv` exclude DNP parts;
  `heart_v2_bom_all.csv` retains them for engineering reference.

## First-board validation

1. Inspect rails, shorts and power-source switchover before fitting electrodes.
2. Verify SWD, USB enumeration/transfer, microSD peak-current writes and RTC
   hold-up.
3. Test ECG only with a simulator or patient-equivalent load first; record input
   noise, protection leakage, lead-off behavior and RLD stability.
4. Measure RF return loss and BLE range in the final enclosure with the intended
   battery and human proximity, then freeze the pi-network population.
5. Confirm battery connector polarity, enclosure clearance and both pogo fixtures
   against the 100 x 32 mm final outline.

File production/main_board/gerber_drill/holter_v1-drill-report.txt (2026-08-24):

Drill report for holter_v1.kicad_pcb
Created on 2026-08-24T21:37:02

Copper Layer Stackup:
    =============================================================
    L1 :  F.Cu                      front
    L2 :  In1.Cu                    in1
    L3 :  In2.Cu                    in2
    L4 :  B.Cu                      back

Drill file 'holter_v1-PTH.drl' contains
    plated through holes:
    =============================================================
    T1  0.200mm  0.0079"  (253 holes))
    T2  0.200mm  0.0079"  (25 holes))

    Total plated holes count 278

Drill file 'holter_v1-NPTH.drl' contains
    unplated through holes:
    =============================================================

    Total unplated holes count 0

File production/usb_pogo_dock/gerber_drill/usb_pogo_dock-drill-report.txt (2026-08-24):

Drill report for usb_pogo_dock.kicad_pcb
Created on 2026-08-24T21:37:13

Copper Layer Stackup:
    =============================================================
    L1 :  F.Cu                      front
    L2 :  B.Cu                      back

Drill file 'usb_pogo_dock-PTH.drl' contains
    plated through holes:
    =============================================================
    T1  0.200mm  0.0079"  (3 holes))
    T2  0.300mm  0.0118"  (5 holes))
    T3  0.350mm  0.0138"  (6 holes))
    T4  0.600mm  0.0236"  (4 holes)  (with 4 slots)
    T5  1.000mm  0.0394"  (4 holes))

    Total plated holes count 22

Drill file 'usb_pogo_dock-NPTH.drl' contains
    unplated through holes:
    =============================================================
    T1  0.650mm  0.0256"  (2 holes))
    T2  2.200mm  0.0866"  (4 holes))

    Total unplated holes count 6

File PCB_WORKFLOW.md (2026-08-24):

# PCB_WORKFLOW

## Start command

对 Codex 只需要说：

**按 `PCB_WORKFLOW.md` 从头到尾完成新版 PCB。使用项目里的 heart-pcb skill；自行做合理工程判断并继续，只有缺少无法推导的外部尺寸/器件信息时才停下来问我。**

## 1. Setup

先读 `.agents/skills/heart-pcb/SKILL.md`、`reference/HARDWARE_SPEC_V1.md` 和 `reference/DECISIONS.md`。

确认 KiCad 10 / `kicad-cli` 可用。若没有 `kicad-tool`，安装：

```bash
sudo apt install -y pipx
pipx ensurepath
pipx install "git+https://github.com/mash/kicad-skills.git"
```

用 `kicad-tool` 做查询、render、ERC/DRC/validate；需要实际放置和布线时使用 KiCad 自带 Python/`pcbnew` API。不要直接靠字符串批量改 KiCad 文件。

## 2. Start clean

从 `reference/kicad/` 复制原理图、project、symbol/footprint libraries 到 `hardware/heart_v2/`，建立新的 PCB 文件。

**不要复制或继续修改 `Old/**/.kicad_pcb` 的 tracks/vias，也不要把旧 Freerouting 结果当布局起点。** 旧版只用于查电气连接、器件选择或机械事实。

先确保 schematic/ERC 没有明显问题，再从零做 placement。

## 3. Placement first

按功能块摆：ECG 接口/保护/ADS1294R → 电源 → STM32/时钟 → microSD/USB → RF/天线。连接紧密的器件靠近，去耦贴引脚，器件方向尽量统一；让关键网络天然短，而不是靠后面绕线补救。

L2 保持连续 GND reference。天线端远离 ECG 输入并保留 keepout。先把 RF、晶振、SMPS、ECG 模拟区布局定好，再处理普通数字器件。

## 4. Human-style routing

**禁止 Freerouting 或任何全局自动布线作为最终 PCB。**

按优先级手工式布线：RF → HSE/LSE/SMPS → ECG/RLD/WCT → USB D+/D- → microSD → 电源 → 普通 GPIO。

目标是“一眼像熟练工程师画的板”：
- 走线短、直接，以 45° 为主；同组总线平行、间距一致、扇出规律。
- 能同层就同层；没有必要就不换层、不打 via、不绕蛇形、不随机折返。
- 电源线按电流加宽；普通信号不要为了逃线到处压 0.10 mm。
- USB 成对走、尽量等长且少换层；RF feed 尽量极短、无 via、连续地参考；ECG 输入四路保持对称并远离数字/RF。
- 发现某根线必须大绕路时，优先重新移动器件，而不是接受难看的走线。

每完成一个关键区域就 render 看图；如果视觉上像自动路由的 spaghetti，就重摆/重走。不要仅以 DRC=0 判断完成。

## 5. Finish

补 GND zones、必要 stitching vias 和整洁丝印；再次 render 全板正反面检查元件方向、线束、过孔、回流路径和机械边界。

最终至少做到：
- ERC 0 error，DRC 0 violation，0 unconnected pads。
- RF/USB/SD/ECG 关键网络经过视觉检查和长度/via 检查。
- 输出最终 KiCad 源文件、Gerber/drill、BOM/CPL、装配/铜层 PDF 和简短 audit。

完成后直接汇报最终文件、关键指标和仍需首板实测的项目。不要为了“更保险”额外扩展几十个检查步骤。

> 这是研究原型。接人体前仍需先用 ECG simulator / patient-equivalent load 做电气与噪声验证。

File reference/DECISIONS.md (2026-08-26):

# Holter V1 Implementation Decisions

**冻结日期**：2026-08-23
**决策人**：用户授权“全部按推荐方案”；以下内容作为 V1 原理图、PCB、BOM 和生产文件的统一依据。

## 1. 使用边界

- 仅用于研究和个人工程验证，不用于诊断、监护决策或临床用途。
- 主板没有患者侧隔离，也没有除颤防护。
- 人体电极连接时禁止连接 USB/Pogo；主板和夹具均标注 `DISCONNECT ELECTRODES BEFORE USB`。
- USB 夹具与 ECG 线缆插头采用机械互锁结构，使二者不能同时就位。

## 2. 制造与机械

| 项目 | 决策 |
|---|---|
| 厂商目标 | JLCPCB Standard PCBA |
| 首批数量 | 5 套主板 + 5 套 USB-Pogo 夹具板 |
| 主板 | 100.0 mm × 32.0 mm 圆角长板；北侧新增 2.0 mm 服务触点带 |
| 层叠 | 4 层，0.8 mm；L1 signal/components、L2 GND reference（两处已审计的局部 3V0_D 短桥）、L3 power/signal、L4 signal |
| 表面处理 | ENIG |
| 装配 | 主板主要器件全部在顶层；底层仅 Pogo/SWD 接触面、过孔和必要铜 |
| 外壳 | 金属主体；天线端使用塑料 RF 端盖/窗口，要求闭盖 BLE |
| 电池 | 带保护 1S 3.7 V、约 1000 mAh、低于 5 mm 厚；与主板同平面独立仓，不叠放 |

> 2026-08-26 布局实施例外：用户明确授权在确有必要时扩大板框。最终板仅向北侧
> 增加 2.0 mm（由 100 × 30 mm 改为 100 × 32 mm），用于把 USB 与 SWD Pogo
> 分成两条整齐、可标注的服务排；ECG、天线和卡座所在其余机械基准不变。外壳图
> 和夹具图必须以 100 × 32 mm 最终板框更新。

## 3. 已选关键器件

| 功能 | 制造商料号 | 封装/说明 |
|---|---|---|
| ECG AFE | TI `ADS1294RIZXGT` | NFBGA-64，8 × 8 mm，0.8 mm pitch |
| MCU | ST `STM32WB55RGV6` | VFQFPN68，8 × 8 mm；1 MB Flash |
| IMU | Bosch `BMI270` | LGA-14，3.0 × 2.5 mm |
| 电源选择 | TI `TPS2116DRLR` | SOT-5X3-8；USB 优先、反向电流阻断 |
| 3.0 V 数字 LDO | TI `TPS7A2130PDBVR` | 500 mA，SOT-23-5 |
| 3.0 V 模拟 LDO | TI `TPS7A2030PDBVR` | 300 mA，SOT-23-5 |
| 3.3 V USB LDO | TI `TPS7A2033PDBVR` | 300 mA，SOT-23-5；仅由 VBUS 供电 |
| microSD 负载开关 | TI `TPS22918DBVR` | SOT-23-6；软启动、快速放电 |
| BLE 匹配滤波器 | ST `MLPF-WB55-01E3` | 1.0 × 1.6 mm WLCSP，匹配 STM32WB55Cx/Rx |
| BLE 天线 | Johanson `2450AT18A100E` | 3.2 × 1.6 mm 芯片天线；量产前实机调匹配 |
| microSD 卡座 | Molex `104031-0811` | 水平 push-pull，1.42 mm，带检测 |
| ECG 板端 | Molex `78171-5006` | Pico-EZmate 6-pin，1.2 mm pitch |
| ECG 线端 | Molex `78172-5006` | 6-pin housing；RA/LA/LL/RL/V5/shield-detect |
| 电池板端 | Molex `78171-0002` | Pico-EZmate 2-pin |
| 电池线端 | Molex `78172-0002` | 2-pin housing |

如果 JLC 基础/扩展库没有关键 IC，则使用 JLC 全球代采或由客户预备料；不以“换成电气上不等价的库存料”换取贴装便利。

## 4. 接口与 MCU 引脚冻结

| 信号组 | STM32WB55RGV6 引脚 |
|---|---|
| ADS SPI1 | PA5=SCK、PA6=MISO、PA7=MOSI、PA4=CS |
| ADS 控制 | PB0=PWDN、PB1=RESET、PC0=START、PC1=DRDY |
| microSD SPI2 | PB13=SCK、PB14=MISO、PB15=MOSI；PA10=软件控制 CS |
| microSD | PC2=card detect、PC3=power enable |
| BMI270 I²C1 | PB8=SCL、PB9=SDA、PC4=INT1、PC5=INT2 |
| USB FS | PA11=D-、PA12=D+、PA9=VBUS sense |
| 调试 | PA13=SWDIO、PA14=SWCLK、NRST |
| 其他 | PA0=battery ADC、PB5=status LED、PH3=BOOT0 |

未列出的 GPIO 作为 DNP 测试点或明确 NC，不复用 SWD 引脚。

`SD_CS` 最初分配给 PB12，但该焊盘与 STM32 内部 SMPS/VDD 的必要短支路共用唯一
标准通孔扇出通道。为避免盘中孔、微孔或破坏 SMPS 回路，V1 将片选改到空闲的
PA10；PB12 明确 NC。片选本来就是普通 GPIO 功能，SPI2 的 SCK/MISO/MOSI 硬件
复用保持不变，固件只需将 SD 片选 GPIO 定义为 PA10。

## 5. ECG 通道与保护

- CH1 = LA − RA；CH2 = LL − RA；CH3 = V5 − WCT；CH4 在 V1 中配置内部短路并留测试点。
- RA、LA、LL、V5 每条患者输入采用两段串联限流电阻、低漏电钳位和 C0G EMI 电容；布局在 ECG 接口与 ADS1294R 之间，且保持对称。
- WCT 使用 ADS1294R 内部 WCT mux 组合 RA/LA/LL；WCT 输出仅驱动高阻 CH3N，并按数据手册建议对 AVSS 放置 100 pF。
- RLDOUT 与 RLDINV 之间采用 1 MΩ ∥ 1.5 nF 稳定网络；到 RL 电极使用两只串联 162 kΩ 限流电阻。
- 呼吸阻抗默认不装器件，但保留官方参考拓扑的焊盘。
- 保护网络用于低压、电池供电研究原型的 ESD/EMI/限流，不构成 IEC 60601 合规或除颤防护声明。

## 6. 电源、USB 与换电

- `TPS2116` 选择 USB VBUS 或受保护电池，USB 优先；不存在电池充电路径，也禁止 VBUS 反灌电池。
- `3V0_A` 与 `3V0_D` 分别稳压；STM32 的 `VDDUSB` 使用独立 `3V3_USB`，解决 3.0 V 电源对 USB 供电容差不足的问题。
- microSD 的电源由负载开关控制；所有 SD pull-up 接到开关后的 `3V0_SD`，避免断电反灌。
- RTC VBAT 使用肖特基隔离和低漏电 MLCC 储能，目标保持 60 秒以上；该目标需在首板实测并记录。
- USB/Pogo 顺序固定为 `VBUS / D- / D+ / GND`；另设 5-pad SWD：`3V0_D / GND / SWDIO / SWCLK / NRST`。

## 7. RF 与外壳

- 使用 32 MHz HSE 和 32.768 kHz LSE；STM32 内部 SMPS 网络按 ST AN5165 对应 STM32WB55RG 的推荐值和布局实现。
- RF1 经 `MLPF-WB55-01E3`、50 Ω 受控阻抗走线、可调 π 网络到 `2450AT18A100E`。
- 天线及其 keepout 位于 PCB 最远离 ECG 输入的短边，keepout 内各铜层禁铜，正对塑料 RF 端盖。
- 首板必须在最终外壳、电池和人体邻近条件下测量回波损耗；π 网络的量产值在该测试后冻结。

## 8. 操作默认值

- 无按键；插电池后自动自检、自动继续/新建 recording segment。
- 单颗低电流状态 LED 位于塑料 RF 端盖之后；正常记录时采用很低占空比，允许固件完全关闭。
- microSD 位于远离 ECG 的短边并由小盖板保护。
- BLE 仅用于配置、状态、同步和短时预览；大文件通过断开电极后的 USB 或拔卡导出。

## 9. 仍需由实物验证而非桌面假定的项目

- 芯片天线最终 π 匹配值和闭盖 BLE 范围。
- RLD 环路在人体模拟器/假负载下的稳定性和噪声。
- ECG 输入保护器件的实际漏电、偏置和恢复行为。
- RTC 断电保持时间、microSD 写入峰值和 USB 供电热升。
- 特定批次电池包的保护板阈值、连接器极性和外形公差。

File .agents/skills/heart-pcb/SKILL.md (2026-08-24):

---
name: heart-pcb
description: Rebuild vexpaer's heart PCB with clean, human-style placement and routing in KiCad.
---

# heart-pcb

Follow `PCB_WORKFLOW.md`. Treat `Old/` as archive only.

Core rule: **placement creates easy routing**. Never use Freerouting/global autorouting as the final layout and never copy old PCB tracks/vias into the new board.

Use `kicad-tool` for compact KiCad queries, renders, ERC/DRC and validation. Use KiCad Python/`pcbnew` for placement, tracks, vias, zones and board edits.

For layout:
- group functional blocks and place critical support parts at their pins;
- keep L2 a continuous GND reference;
- route RF/crystals/SMPS/ECG first, then USB/SD/power, then ordinary GPIO;
- prefer short 45° routes, consistent fanout, parallel buses, few vias and few layer changes;
- if a route becomes ugly, move parts and reroute instead of accepting spaghetti;
- keep USB paired, RF extremely short and via-free, ECG inputs symmetric and away from noisy digital/RF areas.

After each major area, render it and inspect the image. A board that passes DRC but looks machine-routed is not finished. Iterate until the whole board is visually orderly, then run final ERC/DRC and manufacturing exports.

Make reasonable engineering choices and keep working. Ask the user only when a genuinely missing external fact prevents progress.

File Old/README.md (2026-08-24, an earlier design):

# vexpaer's heart — Holter V1

`vexpaer's heart` 是一套开源、可制造的研究型便携 ECG 记录器硬件。主板以
ADS1294R、STM32WB55 和 BMI270 为核心，记录 ECG 与运动数据到 microSD，
并提供 BLE 配置以及断开电极后使用的 USB-Pogo 数据接口。

本仓库包含：

- KiCad 10 主板与 USB-Pogo 底座的原理图、PCB 和项目库；
- 可重复生成设计源文件与生产资料的脚本；
- BOM、坐标文件、Gerber、钻孔文件和厂商上传压缩包；
- ERC/DRC 签核报告以及便于人工审阅的 PDF。

## 安全边界

这是研究/个人工程原型，不是医疗器械，不得用于诊断或临床决策。设计没有
医疗级患者隔离，也没有除颤防护。连接人体电极时严禁连接 USB/Pogo；进行
USB 数据导出或刷机前必须先拔下整条电极线缆。

首次接触人体前应先在 ECG 模拟器和假负载上验证输入漏电、RLD 稳定性、噪声、
电源故障和 ESD 恢复行为。实物还必须完成 RF 匹配、最终外壳内 BLE、热、
microSD 写入峰值以及电池极性/保护板验证。

## 目录

- `hardware/holter_v1/`：100 mm × 30 mm、4 层、0.8 mm 主板；
- `hardware/usb_pogo_dock/`：USB-C 转 4 针 Pogo 底座；
- `production/`：可直接交给 PCB/PCBA 厂商的输出和制造说明；
- `pdf/`：原理图、PCB 铜层和装配图 PDF；
- `docs/`：BOM 源数据、引脚审计与 ERC/DRC 报告；
- `tools/`：设计生成与发布导出脚本。

完整需求见 [HARDWARE_SPEC_V1.md](HARDWARE_SPEC_V1.md)，冻结的工程决策见
[DECISIONS.md](DECISIONS.md)。制造前请阅读 [production/README.md](production/README.md)
和 [docs/HARDWARE_AUDIT.md](docs/HARDWARE_AUDIT.md)。

## 重新生成和检查

需要 KiCad 10，并让 `kicad-cli` 位于 `PATH`；也可通过 `KICAD_CLI` 指定可执行文件。

```bash
# 原理图、项目库和 BOM 源数据
python3 tools/generate_hardware.py

# 从已提交的 Freerouting 中间板重复生成正式主板（用 KiCad 自带 Python）
/path/to/kicad-python tools/finish_main_routes.py \
  hardware/holter_v1/routing_source/holter_v1-freerouted-input.kicad_pcb \
  /tmp/holter_v1-rebuilt.kicad_pcb
cp hardware/holter_v1/holter_v1.kicad_pro /tmp/holter_v1-rebuilt.kicad_pro

# USB-Pogo 底座
python3 tools/generate_dock.py
python3 tools/generate_dock_board.py

# 主板几何/物料审计（同样用 KiCad 自带 Python）
/path/to/kicad-python tools/audit_hardware.py
# 或审计临时重建板：
/path/to/kicad-python tools/audit_hardware.py \
  --board /tmp/holter_v1-rebuilt.kicad_pcb \
  --output /tmp/holter_v1-rebuilt-audit.md

# ERC、DRC、PDF、Gerber、钻孔、BOM、CPL 和制造 ZIP
KICAD_CLI=/path/to/kicad-cli python3 tools/export_release.py
```

`generate_board.py` 只生成未布线的主板起点，不属于正式发布流程。仓库中已提交的
`hardware/holter_v1/holter_v1.kicad_pcb` 是正式签核布线版本；重建结果应先在
临时路径完成 ERC/DRC 和几何审计，再替换正式文件。

## 许可

硬件设计和随附文档以 CERN Open Hardware Licence Version 2 — Strongly Reciprocal
（CERN-OHL-S-2.0）发布。完整条款见 `LICENSE`。

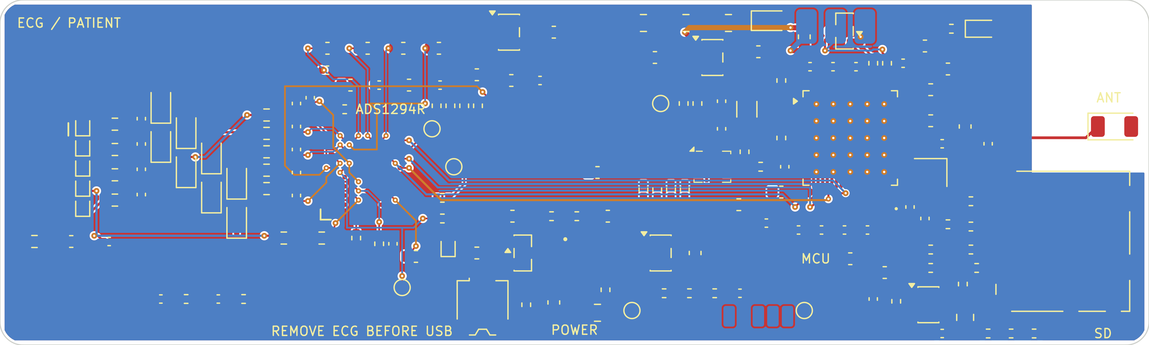
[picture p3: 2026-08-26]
hardware/heart_v2/docs/renders/routing_stage_spi.png

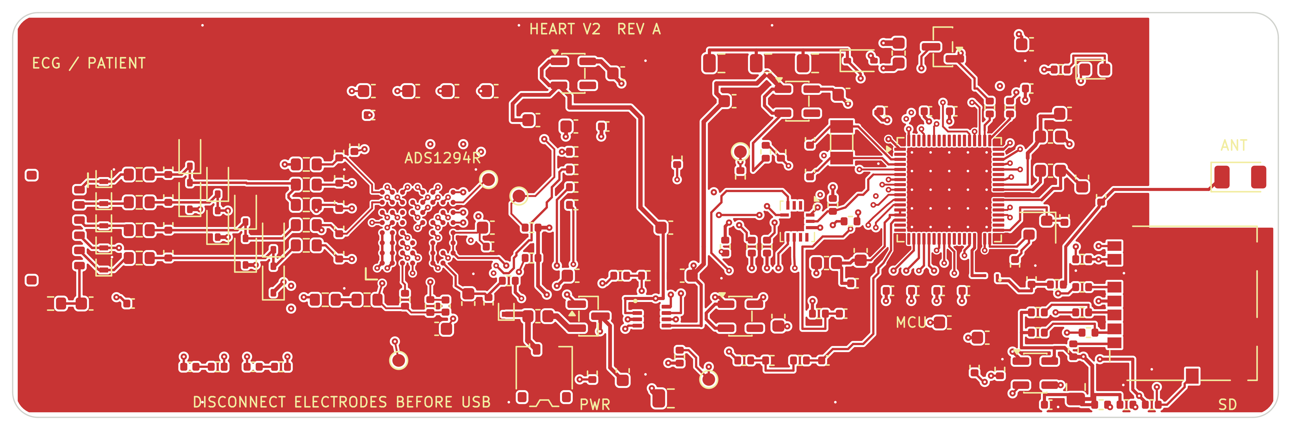
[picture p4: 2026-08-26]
hardware/heart_v2/docs/heart_v2_final_top_routing.png

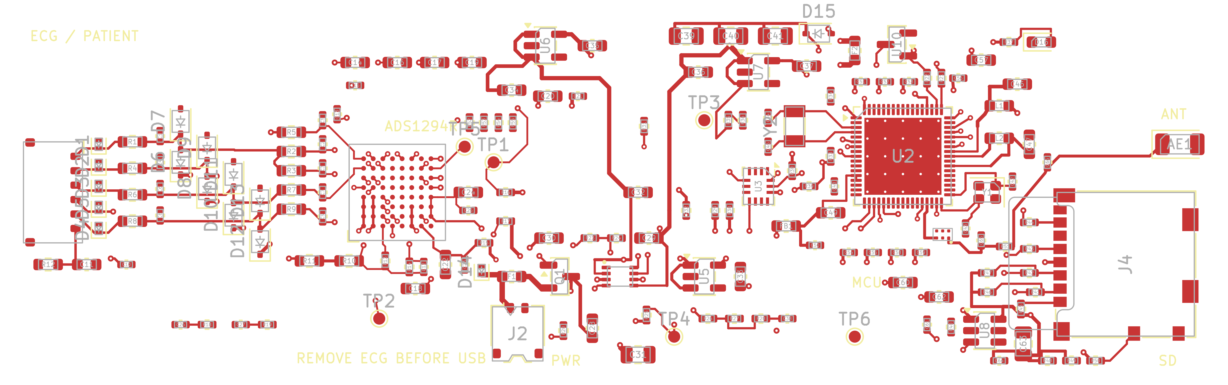
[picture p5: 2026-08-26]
hardware/heart_v2/docs/heart_v2_current_top_routing.png

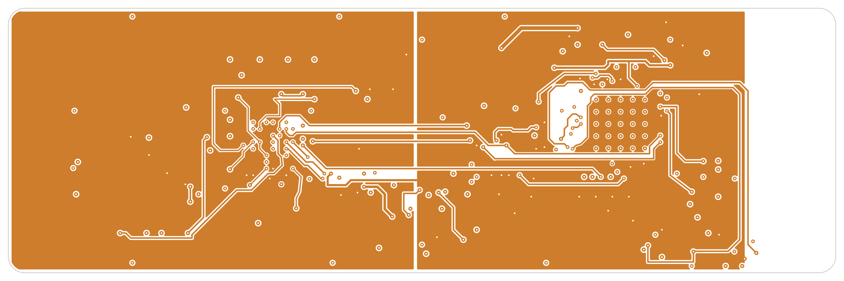
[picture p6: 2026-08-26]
hardware/heart_v2/docs/heart_v2_final_power_layer.png

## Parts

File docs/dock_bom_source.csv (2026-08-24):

Reference | Quantity | Value | Manufacturer | Manufacturer Part Number | Footprint | DNP | Description
J1 | 1 | USB-C USB2.0 | Korean Hroparts Elec | TYPE-C-31-M-12 | Connector_USB:USB_C_Receptacle_HRO_TYPE-C-31-M-12 |  | 16-contact horizontal USB Type-C receptacle
R1 | 1 | 5.1k 1% | Yageo | RC0402FR-075K1L | Resistor_SMD:R_0402_1005Metric |  | Resistor
R2 | 1 | 5.1k 1% | Yageo | RC0402FR-075K1L | Resistor_SMD:R_0402_1005Metric |  | Resistor
D1 | 1 | PESD5V0U1UL | Nexperia | PESD5V0U1UL,315 | Diode_SMD:D_SOD-882 |  | Connector-side VBUS ESD suppressor
F1 | 1 | 0.50A PTC | Bourns | MF-FSMF050X-2 | Fuse:Fuse_0603_1608Metric |  | Resettable fuse
U1 | 1 | TPD2EUSB30DRTR | Texas Instruments | TPD2EUSB30DRTR | Package_TO_SOT_SMD:SOT-23 |  | Two-channel low-capacitance USB 2.0 ESD protection
J2 | 1 | 4x spring pogo | Mill-Max | 0906-series / hand fitted | Dock:Pogo_Dock_4x1_P2.54_Top |  | Four replaceable spring pins in a keyed fixture
R3 | 1 | 1M | Yageo | RC0603FR-071ML | Resistor_SMD:R_0603_1608Metric |  | Resistor
C1 | 1 | 1nF 1kV C0G | KEMET | C1206C102JDGACTU | Capacitor_SMD:C_1206_3216Metric |  | Capacitor
R4 | 1 | 0R DNP | Yageo | RC0603JR-070RL | Resistor_SMD:R_0603_1608Metric | DNP | Optional direct shield bond after EMC evaluation
R5 | 1 | 3.3k | Yageo | RC0402FR-073K3L | Resistor_SMD:R_0402_1005Metric |  | Resistor
D2 | 1 | Green 0603 | Lite-On | LTST-C190KGKT | LED_SMD:LED_0603_1608Metric |  | Low-current status LED

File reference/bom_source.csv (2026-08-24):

Reference | Quantity | Value | Manufacturer | Manufacturer Part Number | Footprint | DNP | Description
AE1 | 1 | 2450AT18A100E | Johanson Technology | 2450AT18A100E | RF_Antenna:Johanson_2450AT18x100_2400-2500Mhz |  | 2.4 GHz chip antenna; terminal 2 is mechanical NC
C1 | 1 | 100p C0G | Murata | GRM1555C1H101JA01D | Capacitor_SMD:C_0402_1005Metric |  | Capacitor
C2 | 1 | 100p C0G | Murata | GRM1555C1H101JA01D | Capacitor_SMD:C_0402_1005Metric |  | Capacitor
C3 | 1 | 100p C0G | Murata | GRM1555C1H101JA01D | Capacitor_SMD:C_0402_1005Metric |  | Capacitor
C4 | 1 | 100p C0G | Murata | GRM1555C1H101JA01D | Capacitor_SMD:C_0402_1005Metric |  | Capacitor
C5 | 1 | 100p C0G | Murata | GRM1555C1H101JA01D | Capacitor_SMD:C_0402_1005Metric |  | Capacitor
C6 | 1 | 100p C0G | Murata | GRM1555C1H101JA01D | Capacitor_SMD:C_0402_1005Metric |  | Capacitor
C7 | 1 | 100p C0G | Murata | GRM1555C1H101JA01D | Capacitor_SMD:C_0402_1005Metric |  | Capacitor
C8 | 1 | 100p C0G | Murata | GRM1555C1H101JA01D | Capacitor_SMD:C_0402_1005Metric |  | Capacitor
C9 | 1 | 100p C0G | Murata | GRM1555C1H101JA01D | Capacitor_SMD:C_0402_1005Metric |  | Capacitor
C10 | 1 | 100p C0G DNP | Murata | GRM1555C1H101JA01D | Capacitor_SMD:C_0402_1005Metric | DNP | Capacitor
C11 | 1 | 1nF 100V C0G | KEMET | C0603C102J1GACTU | Capacitor_SMD:C_0603_1608Metric |  | Capacitor
C12 | 1 | 1.5nF C0G | Murata | GRM1555C1H152JA01D | Capacitor_SMD:C_0402_1005Metric |  | Capacitor
C13 | 1 | 100p C0G | Murata | GRM1555C1H101JA01D | Capacitor_SMD:C_0402_1005Metric |  | Capacitor
C14 | 1 | 10u 6.3V X5R | Murata | GRM188R60J106ME47D | Capacitor_SMD:C_0603_1608Metric |  | Capacitor
C15 | 1 | 100n X7R | Murata | GRM155R71C104KA88D | Capacitor_SMD:C_0402_1005Metric |  | Capacitor
C16 | 1 | 22u 6.3V X5R | Murata | GRM188R60J226MEA0D | Capacitor_SMD:C_0603_1608Metric |  | Capacitor
C17 | 1 | 1u X7R | Murata | GRM188R71C105KA12D | Capacitor_SMD:C_0603_1608Metric |  | Capacitor
C18 | 1 | 1u X7R | Murata | GRM188R71C105KA12D | Capacitor_SMD:C_0603_1608Metric |  | Capacitor
C19 | 1 | 1u X7R | Murata | GRM188R71C105KA12D | Capacitor_SMD:C_0603_1608Metric |  | Capacitor
C20 | 1 | 1u X7R | Murata | GRM188R71C105KA12D | Capacitor_SMD:C_0603_1608Metric |  | Capacitor
C21 | 1 | 100n X7R | Murata | GRM155R71C104KA88D | Capacitor_SMD:C_0402_1005Metric |  | Capacitor
C22 | 1 | 1u X7R | Murata | GRM188R71C105KA12D | Capacitor_SMD:C_0603_1608Metric |  | Capacitor
C23 | 1 | 100n X7R | Murata | GRM155R71C104KA88D | Capacitor_SMD:C_0402_1005Metric |  | Capacitor
C24 | 1 | 1u X7R | Murata | GRM188R71C105KA12D | Capacitor_SMD:C_0603_1608Metric |  | Capacitor
C25 | 1 | 100n X7R | Murata | GRM155R71C104KA88D | Capacitor_SMD:C_0402_1005Metric |  | Capacitor
C26 | 1 | 2.2n C0G DNP | Murata | GRM1555C1H222JA01D | Capacitor_SMD:C_0402_1005Metric | DNP | Capacitor
C27 | 1 | 2.2n C0G DNP | Murata | GRM1555C1H222JA01D | Capacitor_SMD:C_0402_1005Metric | DNP | Capacitor
C28 | 1 | 10u 6.3V X5R | Murata | GRM188R60J106ME47D | Capacitor_SMD:C_0603_1608Metric |  | Capacitor
C29 | 1 | 1u X7R | Murata | GRM188R71C105KA12D | Capacitor_SMD:C_0603_1608Metric |  | Capacitor
C30 | 1 | 1u X7R | Murata | GRM188R71C105KA12D | Capacitor_SMD:C_0603_1608Metric |  | Capacitor
C31 | 1 | 22u 6.3V X5R | Murata | GRM21BR60J226ME39L | Capacitor_SMD:C_0805_2012Metric |  | Capacitor
C32 | 1 | 1u X7R | Murata | GRM188R71C105KA12D | Capacitor_SMD:C_0603_1608Metric |  | Capacitor
C33 | 1 | 10u 6.3V X5R | Murata | GRM188R60J106ME47D | Capacitor_SMD:C_0603_1608Metric |  | Capacitor
C34 | 1 | 1u X7R | Murata | GRM188R71C105KA12D | Capacitor_SMD:C_0603_1608Metric |  | Capacitor
C35 | 1 | 10u 6.3V X5R | Murata | GRM188R60J106ME47D | Capacitor_SMD:C_0603_1608Metric |  | Capacitor
C36 | 1 | 1u X7R | Murata | GRM188R71C105KA12D | Capacitor_SMD:C_0603_1608Metric |  | Capacitor
C37 | 1 | 4.7u X7R | Murata | GRM188Z71A475KE15D | Capacitor_SMD:C_0603_1608Metric |  | Capacitor
C38 | 1 | 100n X7R | Murata | GRM155R71C104KA88D | Capacitor_SMD:C_0402_1005Metric |  | Capacitor
C39 | 1 | 47u 6.3V X5R | Murata | GRM21BR60J476ME15L | Capacitor_SMD:C_0805_2012Metric |  | Capacitor
C40 | 1 | 47u 6.3V X5R | Murata | GRM21BR60J476ME15L | Capacitor_SMD:C_0805_2012Metric |  | Capacitor
C41 | 1 | 47u 6.3V X5R | Murata | GRM21BR60J476ME15L | Capacitor_SMD:C_0805_2012Metric |  | Capacitor
C42 | 1 | 8.2p C0G | Murata | GRM1555C1H8R2CA01D | Capacitor_SMD:C_0402_1005Metric |  | Capacitor
C43 | 1 | 8.2p C0G | Murata | GRM1555C1H8R2CA01D | Capacitor_SMD:C_0402_1005Metric |  | Capacitor
C44 | 1 | 10p C0G | Murata | GRM1555C1H100JA01D | Capacitor_SMD:C_0402_1005Metric |  | Capacitor
C45 | 1 | 10p C0G | Murata | GRM1555C1H100JA01D | Capacitor_SMD:C_0402_1005Metric |  | Capacitor
C46 | 1 | 4.7u X7R | Murata | GRM188Z71A475KE15D | Capacitor_SMD:C_0603_1608Metric |  | Capacitor
C47 | 1 | 4.7u X7R | Murata | GRM188Z71A475KE15D | Capacitor_SMD:C_0603_1608Metric |  | Capacitor
C48 | 1 | 100n X7R | Murata | GRM155R71C104KA88D | Capacitor_SMD:C_0402_1005Metric |  | Capacitor
C49 | 1 | 1u X7R | Murata | GRM188R71C105KA12D | Capacitor_SMD:C_0603_1608Metric |  | Capacitor
C50 | 1 | 100n X7R | Murata | GRM155R71C104KA88D | Capacitor_SMD:C_0402_1005Metric |  | Capacitor
C51 | 1 | 100n X7R | Murata | GRM155R71C104KA88D | Capacitor_SMD:C_0402_1005Metric |  | Capacitor
C52 | 1 | 100n X7R | Murata | GRM155R71C104KA88D | Capacitor_SMD:C_0402_1005Metric |  | Capacitor
C53 | 1 | 100n X7R | Murata | GRM155R71C104KA88D | Capacitor_SMD:C_0402_1005Metric |  | Capacitor
C54 | 1 | 100n X7R | Murata | GRM155R71C104KA88D | Capacitor_SMD:C_0402_1005Metric |  | Capacitor
C55 | 1 | 100n X7R | Murata | GRM155R71C104KA88D | Capacitor_SMD:C_0402_1005Metric |  | Capacitor
C56 | 1 | 100n X7R | Murata | GRM155R71C104KA88D | Capacitor_SMD:C_0402_1005Metric |  | Capacitor
C57 | 1 | 4.7u X7R | Murata | GRM188Z71A475KE15D | Capacitor_SMD:C_0603_1608Metric |  | Capacitor
C58 | 1 | 100n X7R | Murata | GRM155R71C104KA88D | Capacitor_SMD:C_0402_1005Metric |  | Capacitor
C59 | 1 | 100n X7R | Murata | GRM155R71C104KA88D | Capacitor_SMD:C_0402_1005Metric |  | Capacitor
C60 | 1 | 1u X7R | Murata | GRM188R71C105KA12D | Capacitor_SMD:C_0603_1608Metric |  | Capacitor
C61 | 1 | 1n X7R | Murata | GRM155R71H102KA01D | Capacitor_SMD:C_0402_1005Metric |  | Capacitor
C62 | 1 | 1u X7R | Murata | GRM188R71C105KA12D | Capacitor_SMD:C_0603_1608Metric |  | Capacitor
C63 | 1 | 22u 6.3V X5R | Murata | GRM21BR60J226ME39L | Capacitor_SMD:C_0805_2012Metric |  | Capacitor
C64 | 1 | 100n X7R | Murata | GRM155R71C104KA88D | Capacitor_SMD:C_0402_1005Metric |  | Capacitor
C65 | 1 | DNP |  |  | Capacitor_SMD:C_0402_1005Metric | DNP | RF pi-network shunt tuning position
C66 | 1 | DNP |  |  | Capacitor_SMD:C_0402_1005Metric | DNP | RF pi-network shunt tuning position
D1 | 1 | PESD5V0U1UL | Nexperia | PESD5V0U1UL,315 | Diode_SMD:D_SOD-882 |  | Connector-side low-capacitance ESD suppressor; characterize leakage
D2 | 1 | PESD5V0U1UL | Nexperia | PESD5V0U1UL,315 | Diode_SMD:D_SOD-882 |  | Connector-side low-capacitance ESD suppressor; characterize leakage
D3 | 1 | PESD5V0U1UL | Nexperia | PESD5V0U1UL,315 | Diode_SMD:D_SOD-882 |  | Connector-side low-capacitance ESD suppressor; characterize leakage
D4 | 1 | PESD5V0U1UL | Nexperia | PESD5V0U1UL,315 | Diode_SMD:D_SOD-882 |  | Connector-side low-capacitance ESD suppressor; characterize leakage
D5 | 1 | PESD5V0U1UL | Nexperia | PESD5V0U1UL,315 | Diode_SMD:D_SOD-882 |  | Connector-side low-capacitance ESD suppressor; characterize leakage
D6 | 1 | BAS116 | Nexperia | BAS116,115 | Diode_SMD:D_SOD-323 |  | Diode
D7 | 1 | BAS116 | Nexperia | BAS116,115 | Diode_SMD:D_SOD-323 |  | Diode
D8 | 1 | BAS116 | Nexperia | BAS116,115 | Diode_SMD:D_SOD-323 |  | Diode
D9 | 1 | BAS116 | Nexperia | BAS116,115 | Diode_SMD:D_SOD-323 |  | Diode
D10 | 1 | BAS116 | Nexperia | BAS116,115 | Diode_SMD:D_SOD-323 |  | Diode
D11 | 1 | BAS116 | Nexperia | BAS116,115 | Diode_SMD:D_SOD-323 |  | Diode
D12 | 1 | BAS116 | Nexperia | BAS116,115 | Diode_SMD:D_SOD-323 |  | Diode
D13 | 1 | BAS116 | Nexperia | BAS116,115 | Diode_SMD:D_SOD-323 |  | Diode
D14 | 1 | PESD5V0U1UL | Nexperia | PESD5V0U1UL,315 | Diode_SMD:D_SOD-882 |  | Bidirectional low-leakage ESD suppressor
D15 | 1 | BAT54H | Nexperia | BAT54H,115 | Diode_SMD:D_SOD-323 |  | Diode
D16 | 1 | GREEN 0603 | Wurth Elektronik | 150060VS75000 | LED_SMD:LED_0603_1608Metric |  | Low-current status LED
F1 | 1 | 0.50A PTC | Bourns | MF-FSMF050X-2 | Fuse:Fuse_0603_1608Metric |  | Resettable fuse
F2 | 1 | 0.50A PTC | Bourns | MF-FSMF050X-2 | Fuse:Fuse_0603_1608Metric |  | Resettable fuse
FB1 | 1 | 600R@100MHz | Murata | BLM15AG601SN1D | Inductor_SMD:L_0603_1608Metric |  | Inductor or ferrite bead
J1 | 1 | ECG_HARNESS | Molex | 78171-5006 | Holter:Molex_Pico-EZmate_78171-5006 |  | Molex Pico-EZmate six-position ECG harness connector
J2 | 1 | PROTECTED_1S_LIPO | Molex | 78171-0002 | Connector_Molex:Molex_Pico-EZmate_78171-0002_1x02-1MP_P1.20mm_Vertical |  | Protected 1S LiPo connector
J4 | 1 | MICROSD | Molex | 104031-0811 | Connector_Card:microSD_HC_Molex_104031-0811 |  | Molex 104031-0811 microSD push-pull connector with card detect
L1 | 1 | 10nH | Murata | LQG15HN10NJ02D | Inductor_SMD:L_0603_1608Metric |  | Inductor or ferrite bead
L2 | 1 | 2.2uH | Murata | LQM18PN2R2MFRL | Inductor_SMD:L_0603_1608Metric |  | Inductor or ferrite bead
Q1 | 1 | DMP2035U | Diodes Incorporated | DMP2035U-7 | Package_TO_SOT_SMD:SOT-23 |  | P-channel high-side reverse-polarity protection MOSFET
R1 | 1 | 47.5k 0.1% | Yageo | RT0603BRD0747K5L | Resistor_SMD:R_0603_1608Metric |  | Resistor
R2 | 1 | 47.5k 0.1% | Yageo | RT0603BRD0747K5L | Resistor_SMD:R_0603_1608Metric |  | Resistor
R3 | 1 | 47.5k 0.1% | Yageo | RT0603BRD0747K5L | Resistor_SMD:R_0603_1608Metric |  | Resistor
R4 | 1 | 47.5k 0.1% | Yageo | RT0603BRD0747K5L | Resistor_SMD:R_0603_1608Metric |  | Resistor
R5 | 1 | 47.5k 0.1% | Yageo | RT0603BRD0747K5L | Resistor_SMD:R_0603_1608Metric |  | Resistor
R6 | 1 | 47.5k 0.1% | Yageo | RT0603BRD0747K5L | Resistor_SMD:R_0603_1608Metric |  | Resistor
R7 | 1 | 47.5k 0.1% | Yageo | RT0603BRD0747K5L | Resistor_SMD:R_0603_1608Metric |  | Resistor
R8 | 1 | 47.5k 0.1% | Yageo | RT0603BRD0747K5L | Resistor_SMD:R_0603_1608Metric |  | Resistor
R9 | 1 | 47.5k 0.1% | Yageo | RT0603BRD0747K5L | Resistor_SMD:R_0603_1608Metric |  | Resistor
R10 | 1 | 162k 0.1% | Yageo | RT0603BRD07162KL | Resistor_SMD:R_0603_1608Metric |  | Resistor
R11 | 1 | 162k 0.1% | Yageo | RT0603BRD07162KL | Resistor_SMD:R_0603_1608Metric |  | Resistor
R12 | 1 | 1M | Yageo | RC0603FR-071ML | Resistor_SMD:R_0603_1608Metric |  | Resistor
R13 | 1 | 0R | Yageo | RC0402JR-070RL | Resistor_SMD:R_0402_1005Metric |  | Resistor
R14 | 1 | 1M | Yageo | RC0402FR-071ML | Resistor_SMD:R_0402_1005Metric |  | Resistor
R15 | 1 | 0R | Yageo | RC0402JR-070RL | Resistor_SMD:R_0402_1005Metric |  | Resistor
R16 | 1 | 0R | Yageo | RC0402JR-070RL | Resistor_SMD:R_0402_1005Metric |  | Resistor
R17 | 1 | 0R | Yageo | RC0402JR-070RL | Resistor_SMD:R_0402_1005Metric |  | Resistor
R18 | 1 | 40.2k 0.1% DNP | Yageo | RT0402BRD0740K2L | Resistor_SMD:R_0402_1005Metric | DNP | Resistor
R19 | 1 | 40.2k 0.1% DNP | Yageo | RT0402BRD0740K2L | Resistor_SMD:R_0402_1005Metric | DNP | Resistor
R20 | 1 | 1M | Yageo | RC0402FR-071ML | Resistor_SMD:R_0402_1005Metric |  | Resistor
R21 | 1 | 22R | Yageo | RC0402FR-0722RL | Resistor_SMD:R_0402_1005Metric |  | Resistor
R22 | 1 | 22R | Yageo | RC0402FR-0722RL | Resistor_SMD:R_0402_1005Metric |  | Resistor
R23 | 1 | 300k | Yageo | RC0402FR-07300KL | Resistor_SMD:R_0402_1005Metric |  | Resistor
R24 | 1 | 100k | Yageo | RC0402FR-07100KL | Resistor_SMD:R_0402_1005Metric |  | Resistor
R25 | 1 | 100k | Yageo | RC0402FR-07100KL | Resistor_SMD:R_0402_1005Metric |  | Resistor
R26 | 1 | 1M | Yageo | RC0402FR-071ML | Resistor_SMD:R_0402_1005Metric |  | Resistor
R27 | 1 | 330k | Yageo | RC0402FR-07330KL | Resistor_SMD:R_0402_1005Metric |  | Resistor
R28 | 1 | 1k | Yageo | RC0402FR-071KL | Resistor_SMD:R_0402_1005Metric |  | Resistor
R29 | 1 | 100k | Yageo | RC0402FR-07100KL | Resistor_SMD:R_0402_1005Metric |  | Resistor
R30 | 1 | 100k | Yageo | RC0402FR-07100KL | Resistor_SMD:R_0402_1005Metric |  | Resistor
R31 | 1 | 100k | Yageo | RC0402FR-07100KL | Resistor_SMD:R_0402_1005Metric |  | Resistor
R32 | 1 | 100k | Yageo | RC0402FR-07100KL | Resistor_SMD:R_0402_1005Metric |  | Resistor
R33 | 1 | 100k | Yageo | RC0402FR-07100KL | Resistor_SMD:R_0402_1005Metric |  | Resistor
R34 | 1 | 100k | Yageo | RC0402FR-07100KL | Resistor_SMD:R_0402_1005Metric |  | Resistor
R35 | 1 | 470k | Yageo | RC0402FR-07470KL | Resistor_SMD:R_0402_1005Metric |  | Resistor
R36 | 1 | 680k | Yageo | RC0402FR-07680KL | Resistor_SMD:R_0402_1005Metric |  | Resistor
R37 | 1 | 2.2k | Yageo | RC0402FR-072K2L | Resistor_SMD:R_0402_1005Metric |  | Resistor
R38 | 1 | 4.7k | Yageo | RC0402FR-074K7L | Resistor_SMD:R_0402_1005Metric |  | Resistor
R39 | 1 | 4.7k | Yageo | RC0402FR-074K7L | Resistor_SMD:R_0402_1005Metric |  | Resistor
R40 | 1 | 100k | Yageo | RC0402FR-07100KL | Resistor_SMD:R_0402_1005Metric |  | Resistor
R41 | 1 | 22R | Yageo | RC0402FR-0722RL | Resistor_SMD:R_0402_1005Metric |  | Resistor
R42 | 1 | 22R | Yageo | RC0402FR-0722RL | Resistor_SMD:R_0402_1005Metric |  | Resistor
R43 | 1 | 22R | Yageo | RC0402FR-0722RL | Resistor_SMD:R_0402_1005Metric |  | Resistor
R44 | 1 | 22R | Yageo | RC0402FR-0722RL | Resistor_SMD:R_0402_1005Metric |  | Resistor
R45 | 1 | 47k | Yageo | RC0402FR-0747KL | Resistor_SMD:R_0402_1005Metric |  | Resistor
R46 | 1 | 47k | Yageo | RC0402FR-0747KL | Resistor_SMD:R_0402_1005Metric |  | Resistor
R47 | 1 | 47k | Yageo | RC0402FR-0747KL | Resistor_SMD:R_0402_1005Metric |  | Resistor
R48 | 1 | 47k | Yageo | RC0402FR-0747KL | Resistor_SMD:R_0402_1005Metric |  | Resistor
R49 | 1 | 47k | Yageo | RC0402FR-0747KL | Resistor_SMD:R_0402_1005Metric |  | Resistor
R50 | 1 | 100k | Yageo | RC0402FR-07100KL | Resistor_SMD:R_0402_1005Metric |  | Resistor
R51 | 1 | 0R | Yageo | RC0402JR-070RL | Resistor_SMD:R_0402_1005Metric |  | Resistor
R52 | 1 | 0R | Yageo | RC0402JR-070RL | Resistor_SMD:R_0402_1005Metric |  | Resistor
R53 | 1 | 0R | Yageo | RC0402JR-070RL | Resistor_SMD:R_0402_1005Metric |  | Resistor
R54 | 1 | 0R | Yageo | RC0402JR-070RL | Resistor_SMD:R_0402_1005Metric |  | Resistor
R55 | 1 | 0R | Yageo | RC0402JR-070RL | Resistor_SMD:R_0402_1005Metric |  | Resistor
U1 | 1 | ADS1294RIZXGT | Texas Instruments | ADS1294RIZXGT | Holter:ADS1294R_ZXG |  | TI four-channel 24-bit ECG AFE with RLD, WCT and respiration support
U2 | 1 | STM32WB55RGV6 | STMicroelectronics | STM32WB55RGV6 | Package_DFN_QFN:QFN-68-1EP_8x8mm_P0.4mm_EP6.4x6.4mm_ThermalVias |  | ST dual-core BLE/802.15.4 MCU, 1 MB Flash, USB FS
U3 | 1 | BMI270 | Bosch Sensortec | BMI270 | Package_LGA:Bosch_LGA-14_3x2.5mm_P0.5mm |  | Bosch six-axis low-power IMU
U4 | 1 | TPS2116DRLR | Texas Instruments | TPS2116DRLR | Holter:Texas_DRL0008A |  | TI low-IQ two-input power mux with reverse-current blocking
U5 | 1 | TPS7A2130PDBVR | Texas Instruments | TPS7A2130PDBVR | Package_TO_SOT_SMD:SOT-23-5 |  | Fixed-output low-noise LDO in SOT-23-5
U6 | 1 | TPS7A2030PDBVR | Texas Instruments | TPS7A2030PDBVR | Package_TO_SOT_SMD:SOT-23-5 |  | Fixed-output low-noise LDO in SOT-23-5
U7 | 1 | TPS7A2033PDBVR | Texas Instruments | TPS7A2033PDBVR | Package_TO_SOT_SMD:SOT-23-5 |  | Fixed-output low-noise LDO in SOT-23-5
U8 | 1 | TPS22918DBVR | Texas Instruments | TPS22918DBVR | Package_TO_SOT_SMD:SOT-23-6 |  | TI controlled-rise-time load switch
U9 | 1 | MLPF-WB55-01E3 | STMicroelectronics | MLPF-WB55-01E3 | Holter:MLPF-WB55-01E3 |  | ST integrated matching and low-pass filter for STM32WB55Cx/Rx
U10 | 1 | TPD2EUSB30DRTR | Texas Instruments | TPD2EUSB30DRTR | Package_TO_SOT_SMD:SOT-23 |  | Two-channel low-capacitance USB ESD protection
Y1 | 1 | 32MHz 6pF | NDK | NX2016SA-32M-EXS00A-CS06465 | Crystal:Crystal_SMD_2016-4Pin_2.0x1.6mm |  | Four-pad crystal
Y2 | 1 | 32.768kHz 7pF | NDK | NX3215SA-32.768K-STD-MUA-14 | Crystal:Crystal_SMD_3215-2Pin_3.2x1.5mm |  | Two-pad crystal

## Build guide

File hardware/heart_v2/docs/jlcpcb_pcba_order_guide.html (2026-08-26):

# Heart V2 Rev A 嘉立创 PCB + SMT 贴片下单实操教程

这份文档对应仓库里已经冻结的新版板：100 × 32 mm、四层、0.8 mm、所有 SMT 元件在顶层，底面只保留 USB/SWD 裸接触结构。照着顺序上传、匹配、检查，就能把“打板”和“贴片”作为同一个嘉立创订单完成。

文档版本：2026-08-26 · 适用于本目录中的 Heart V2 Rev A 输出；嘉立创页面的实时价格、库存、可选工艺和审核结果始终以你下单当天页面为准。

4 层 / 0.8 mm100 × 32 mm，圆角 2 mm

152 个贴片位BOM 与 CPL 已逐项对齐

ERC / DRC = 0当前源文件检查通过

单面贴片优先实际装配面为顶层

## 0. 先看结论：怎么选才不会把板子下错

推荐的动作是：上传本目录的制造压缩包，添加 PCBA，使用已经生成的 BOM 和 CPL，逐条确认嘉立创实际匹配的料号，最后再付款。

推荐路径 在嘉立创报价页先尝试 四层 / 0.8 mm / 单面贴片 / Economic PCBA。本板的 152 个可贴片元件都在顶层，100 × 32 mm 也落在经济型页面通常接受的小板尺寸范围内。

必须确认表面处理 本版生产目标写的是 ENIG，USB/SWD 是裸金属接触点。嘉立创当前能力页对 Economic PCBA 的板厚、表面处理组合可能和 Standard PCBA 不同；如果 0.8 mm + ENIG 在 Economic 页面不可选，先停在报价页，向嘉立创工程确认“经济型能否按 ENIG 做”或改走 Standard/加工艺边。不要为了能下单而悄悄改成 HASL，也不要直接改源 PCB。

不要把这块板当医疗成品 这是非隔离研究原型，没有患者侧 USB 隔离或除颤保护。人体电极接好时禁止插 USB；首板必须先用 ECG 模拟器或等效负载验证。

## 1. 你会拿到什么：文件角色先分清

所有链接都是相对于本 HTML 文件的本地链接。下单时最重要的是三个文件：Gerber 压缩包、BOM、CPL。PDF 用来人工检查，不是替代 Gerber/CPL 的上传文件。

heart_v2_fab_revA.zip给 PCB 制造的 Gerber、钻孔、IPC-D-356。PCB 报价页上传这个压缩包。

heart_v2_bom.csv给贴片订单的装配 BOM；DNP 已排除，包含 152 个实际装配位所属的料组信息。

heart_v2_cpl.csv给贴片机的坐标文件；当前全部为 top，坐标以成品板物理左下角为原点，均为正数。

heart_v2_bom_all.csv工程参考用，包含 DNP。第一次 PCBA 下单不要上传它，除非你明确要把 DNP 位置改成装配位。

heart_v2_assembly_top.pdf1:1 顶层装配图，用来核对参考号、极性、芯片方向和大件位置。

heart_v2_assembly_bottom.pdf1:1 镜像底层图。J3/J5 裸接触点仍画在这里，但它们不在 CPL 中。

AUDIT.md布局、关键网络、层叠例外、制造注意事项和首板测试记录。

heart_v2.kicad_pcb可追溯源文件；正常下单不上传它替代 Gerber，也不要在网页端临时修改它。

本次已经修正的装配边界 J3、J5 是 USB/SWD pogo 裸接触结构，TP1-TP6 是独立测试焊盘，不是 SMT 元件；它们仍在 PCB 铜箔和装配图中，但已明确从 BOM/CPL 排除。J1、J2、J4 以及顶层电阻、电容、二极管、晶振、芯片、天线等才交给贴片机。

## 2. 下单前准备：先把会卡住报价的事情做完

### 准备资料

- 嘉立创账号、收货地址、发票/税务信息。
- 本教程所在目录中的 fab ZIP、BOM、CPL。
- 对天线、连接器和芯片的替代料有明确态度：默认不接受“相近料自动替换”。
- 首板数量、是否需要焊接电池线/线束、是否要额外裸板。

### 先看这三个物理问题

- 板厚是 0.8 mm，不要被默认值改成 1.6 mm。
- 100 × 32 mm 是成品板，不含可能新增的工艺边。
- ENIG 对 pogo 接触耐磨更友好；若页面只给 HASL，先找工程确认。

### 板上有哪些故意不装的位

DNP（Do Not Populate）为：C10、C26、C27、C65、C66、R18、R19。它们用于调试、射频匹配或预留，不应在第一版自动装上。以 heart_v2_bom.csv 为准即可；不要用 heart_v2_bom_all.csv 覆盖它。

### 下单前做一个离线核对

打开 BOM 和 CPL，用表格软件只读查看也可以，但不要改列名、参考号、坐标和角度。当前应满足：BOM 展开的参考号集合 = CPL 参考号集合 = 152 个，且 CPL 的 Side 全部为 top。J3、J5、TP1-TP6 不出现是正确的，不是漏件。

## 3. 嘉立创 PCB 订单：从裸板报价开始

1

进入 PCB 报价登录嘉立创，进入 PCB 订单/在线下单，上传 heart_v2_fab_revA.zip。不要把整个 Git 仓库压成一个包上传，避免旧的 WIP 文件被识别。

2

确认识别出来的层数和尺寸页面应识别为 4 layers、外形约 100 × 32 mm。若识别出 2 层、尺寸异常、开槽或外形异常，先取消上传重新检查 Gerber，不要点击“继续下单”硬过。

3

选择板厚和表面处理板厚选 0.8 mm；表面处理优先 ENIG。若组合不可选，保留页面截图/订单号并咨询工程，说明板上有 J3/J5 裸 pogo 接触区和 0.8 mm 四层结构。

4

确认阻焊、铜厚、颜色和数量颜色不是电气关键；铜厚按报价页默认能力即可，但不要让系统为了低价改变层叠。数量先按首板验证需要填写，留意低数量、加急和拼板的影响。

5

检查工程审核备注提交前把下面这句话放进备注或工程沟通：Heart V2 Rev A，4L/0.8 mm，100x32 mm，顶层全 SMT；J3/J5 为底面裸 pogo 接触铜，不装料；请确认 ENIG 与小板 PCBA 工艺可行。

不要把“板子能报价”当成“贴片能报价”PCB 裸板识别成功，只说明 Gerber 可制造；PCBA 还要单独通过元件库存、封装、板边/工艺边、贴片面和料号匹配审核。

## 4. PCBA 工艺选择：经济型还是标准型

本板的关键优势是“真正需要机器放置的元件全部在顶层”。这使单面贴片最干净，也避免底面把 pogo 接触区和治具空间占掉。

项目 | Economic PCBA（首选起点） | Standard PCBA（遇到限制再考虑）
贴片面 | 适合本板：单面，全部 SMT 在顶层 | 支持单面/双面，但流程和费用可能更高
本板尺寸 | 100 × 32 mm 通常更匹配经济型小板范围 | 当前能力页列出更大的最小单板尺寸；可能需要工艺边或拼板确认
板厚 / 层数 | 当前能力页通常覆盖 4 层和 0.8 mm，但以报价页可选项为准 | 能力更宽，但仍必须核对具体 stack-up
工艺边 / 定位孔 | 页面可能允许不加边；要确认 pogo 治具是否需要 | 通常会要求工艺边/定位特征，新增部分不能碰到成品铜和接触区
表面处理 | 若没有 0.8 mm + ENIG 组合，先停单咨询 | 可能更容易取得 ENIG，但小板尺寸和加边需工程确认
适用建议 | 先报价 单面、4L、0.8 mm、ENIG（若可选） | 有条件 只有在工艺边/小板/表面处理被经济型拒绝时采用

判断原则 不是“标准型一定更好”，而是要让嘉立创明确回答：这个 100 × 32 mm 的四层 0.8 mm 小板，带底面 pogo 接触铜、顶层全贴片，能否按 ENIG 完成 PCBA。拿到工程确认后再选对应方案。标准型若自动加 5 mm 工艺边，要在生产预览中确认边不会妨碍 J3/J5 的接触和你的夹具。

## 5. 上传 BOM / CPL：文件不要传反

1

在 PCBA 页面开启贴片服务在裸板配置完成后选择 PCBA/Assembly，进入 BOM 和 Pick-and-Place/ Centroid 文件上传步骤。嘉立创通常不能把外厂已经做好的裸板直接拿来装配，最好由同一订单完成 PCB 制造和贴片。

2

BOM 选择 heart_v2_bom.csv它是去掉 DNP 的装配清单。不要上传 heart_v2_bom_all.csv 作为第一版装配 BOM；后者仅用于工程追溯。

3

CPL 选择 heart_v2_cpl.csv选择双面/两面解析也不影响结果，因为文件里的有效坐标全部是 top。若网页显示 bottom 有 0 个元件，这是正确的。

4

确认列映射本文件的列为 Ref, Val, Package, PosX, PosY, Rot, Side；BOM 的列为 References, Value, Footprint, Manufacturer, MPN, Datasheet, Quantity, DNP。如果上传器让你手动选择字段，请把 References/Reference、Value/Comment、Footprint、Manufacturer、MPN 对应到它的同义字段。

5

保持坐标单位为 mmCPL 是毫米坐标，原点是成品板物理左下角，X/Y 都是正数。不要勾选 inch，不要在 Excel 里给 X/Y 加负号，也不要按 PDF 视觉方向镜像坐标。

上传后应该看到的结果参考号总数约 152；贴片面为 top；没有 J3、J5、TP1-TP6；DNP 位置没有要求选料。若出现 154 个、出现 bottom 或出现任意 J3/J5/TP1-TP6，立刻删掉这次文件重新上传，不要用网页里的“自动修复”掩盖问题。

为什么 BOM 不是“所有焊盘”的清单？

BOM 描述的是要购买和装配的元件；CPL 描述贴片机要去放置的元件中心点。J3/J5 的铜接触面是板上功能结构；TP1-TP6 是测试焊盘；它们都不是需要购买的 SMT 料。它们必须留在 Gerber 和 PCB 上，却不能出现在贴片机坐标清单。

## 6. 元件匹配：最容易“看起来成功、实际装错”的一步

嘉立创会把 BOM 行映射到可采购的库存料。工程师要审核的是“制造商 + 完整 MPN + 封装 + 关键电气规格”是否同一个东西，而不只是电阻值或芯片简称。

### 每一行都按这个顺序确认

1. 参考号：数量、合并范围是否正确，例如 C1-C9,C13 代表 10 个位置。
2. 制造商：没有品牌替代授权时，不要把 Murata、Nexperia、TI、ST、Bosch 等自动换成同值杂牌。
3. MPN：完整核对后缀，尤其是精度、温度、额定电压、封装和环保后缀。
4. 封装：0402/0603、SOT-23、QFN/BGA 等必须与 BOM、CPL、PDF 三者一致。
5. 库存与批次：优先选择嘉立创标注的可采购、可按期交付料；缺货不要无提示替换。
6. 极性/方向：二极管、LED、芯片、晶振、天线、连接器必须保留正确的第一脚方向。

### 这块板的料号风险点

- U1：ADS1294RIZXGT，模拟前端，不能用“同 ADS1294”模糊替代。
- U2：STM32WB55RGV6，主控和无线芯片，后缀/封装必须完全一致。
- U3：BMI270，惯导芯片，方向和封装基准要与顶层 PDF 对照。
- U9：MLPF-WB55-01E3，射频滤波器，替代会改变 RF 匹配。
- AE1：2450AT18A100E，天线不可按“2.4G 天线”随便替换。
- J1/J2/J4：Molex 连接器，机械高度、锁扣方向和料号要一致。
- Y1/Y2：两只不同频率、不同负载电容的 NDK 晶振，不能互换。
- D1-D15：保护/整流器件，型号后缀和封装会影响漏电与钳位。

出现“未匹配 / 缺料 / Extended / 替代料”怎么办先记录参考号和嘉立创推荐 MPN，再回看本 BOM 的 Manufacturer/MPN。只有在电气、机械、库存、交期都接受时才手动批准替代；任何“自动选择相近料”都不应在首板无记录地通过。

本项目 BOM 目前用制造商 MPN 作为主要匹配依据，未预填 LCSC 内部编号。若上传器要求 LCSC Part #，在嘉立创料号搜索结果里逐条选择与制造商 MPN、封装完全一致的条目，并把最终选择导出/截图留档。

## 7. 摆件、极性和 DFM 审查：付款前必须看图

不要只看数量和总价。把网页的 placement preview 与本地 1:1 PDF 并排打开，放大到芯片和二极管级别，再确认一次。

### 顶层图逐项检查

- U1/U2/U3/U4-U10 的 Pin 1 标记和丝印方向。
- D1-D16、DNP 预留位的极性标记。
- Y1/Y2 的焊盘方向、J1/J2/J4 插接方向。
- AE1 天线位置没有被贴片预览移动。
- 0402/0603 电容电阻没有被合并到错误参考号。

### 底层图逐项检查

- 有效贴片元件数量应为 0；不要让系统把 pogo 当成器件。
- J3 的 USB 顺序为 VBUS / D- / D+ / GND。
- J5 的底面丝印给出了 SWD 左到右顺序。
- 底面接触区和你的 pogo 治具方向一致。

### 旋转角度不要“凭感觉修”

CPL 的 Rot 是以元件库基准为参考的机器角度，不等于你在镜像 PDF 上看到的文字方向。嘉立创预览若显示红点、Pin 1 或极性标记，应回到 1:1 顶层图核对；只有确认坐标原点、层、封装基准都一致后才改。不要为了让文字朝上而整体加 90° 或镜像。

### 特别看三组布局边界

区域 | 检查重点 | 通过标准
ECG 左侧 | J1、保护二极管、串阻链 | 连接器入口顺序不变，保护链没有漏贴/错贴
MCU / USB / SWD | U2、U10、J3、J5 | U2/U10 在顶层贴，J3/J5 只保留底面铜接触，不在 CPL
RF 右侧 | U9、L1、匹配电容、AE1 | RF 元件位置和天线 keepout 不被工艺边、贴片偏移或替代料破坏

网页预览不清楚就不要付款要求客服/工程提供清晰的装配预览或生产文件。尤其是 QFN/BGA、天线、连接器和二极管，模糊缩略图不足以做方向确认。

## 8. 报价、付款、生产文件和收货

1

处理费用异常芯片、天线、连接器可能触发扩展料、单独采购、X-Ray/检验或工程费。不要只看“最低价”，先看交期、替代料、贴片面和工艺边。

2

下载或截图生产确认页保留最终 BOM 匹配表、CPL 预览、板厚/表面处理、工艺边、数量、交期和备注。订单号要和这些文件一起归档。

3

付款前做最终点击检查确认没有被自动勾选的 DNP，没有未审核的替代料，没有从 0.8 mm 变成 1.6 mm，没有从 ENIG 变成 HASL，没有从单面贴片变成双面贴片。

4

收货先不接电极拿到板后先按本页第 9 节做外观、阻值、限流上电、SWD、USB 和 SD 验证。确认 USB 时电极必须断开。

### 收到的每块板都检查

- 板边、圆角、工艺边是否影响成品尺寸和夹具。
- 丝印参考号、Pin 1、二极管/LED 极性是否清楚。
- 焊桥、少锡、立碑、偏移、连接器翘起、芯片方向。
- 底面 J3/J5 接触铜是否平整、无阻焊覆盖、与治具相符。
- 天线区域无残留铜、异物或被工艺边挡住。

## 9. 第一块板验证：按风险从低到高

先确认板没有短路，再加功能，再接外部电极。每一步记录电源电压、限流、现象和板号，出现异常就停止继续加压。

### A. 无电检查

1. 显微镜看电源、QFN/BGA、连接器和天线。
2. 测 VBAT、3V0、3V0_D 对 GND 的电阻。
3. 确认电池连接器极性、USB 屏蔽和 pogo 治具没有短接。

### B. 限流上电

1. 先用限流电源/电池模拟路径，不接人体、不接电极。
2. 观察 3V0/3V0_D 上电顺序和静态电流。
3. 检查发热、掉压、反复复位。

### C. 数字接口

1. 用 SWD 连接 J5，确认识别、擦写、复位。
2. 断开电极后测试 USB 枚举和持续传输。
3. 插 microSD，做格式化、读写和峰值电流测试。

### D. 传感器、无线和模拟

1. 检查 RTC 后备、IMU 数据和主控时钟稳定性。
2. 在最终外壳、预定电池和人体接近条件下测 BLE 距离、RF 回波/匹配；DNP 的 C65/C66 等匹配位要根据实测决定，不能盲焊。
3. ECG 只接 ECG 模拟器或患者等效负载，记录噪声、输入保护漏电、lead-off 和 RLD 稳定性。
4. 完成模拟器验证并确认 USB 断开后，才考虑任何人体连接；这不是医疗安全认证。

绝对不要省略电极连接状态下插 USB。该板没有患者侧 USB 隔离；PC、充电器和示波器地可能把危险电流路径带到人体侧。

## 10. 红线与排障表

现象 | 先做什么 | 不要做什么
CPL 多出 J3/J5/TP1-TP6 | 重新下载仓库内 CPL；确认使用的是最新输出 | 不要在网页上随意删除一半参考号后付款
BOM/CPL 数量不一致 | 按参考号展开比较；检查是否误传 BOM all | 不要用“自动忽略缺失位”掩盖不一致
网页提示底面有贴片 | 确认选择的 CPL 是本目录文件，Side 应全为 top | 不要把整份坐标镜像或旋转
ENIG/0.8 mm 不可选 | 截图配置并问工程，评估 Standard + 工艺边 | 不要未经确认改 HASL 或 1.6 mm
芯片/天线缺货 | 记录候选 MPN，回到电气/机械规格逐项批准 | 不要仅按阻值、封装或“同功能”自动替代
收到板无法上电 | 限流、断开外设，测电源到 GND 电阻和各路压降 | 不要直接提高电源电压或绕过限流
USB 不枚举 | 先查 J3 顺序、U10 方向、USB_DM/DP 连通和供电 | 不要一边接电极一边插 USB 试错
ECG 噪声或 RLD 异常 | 回到模拟器/等效负载，记录保护链和供电纹波 | 不要用人体替代实验仪器排故

以下任一项出现，停止付款或停止上电板厚/层数不符；表面处理未经确认；CPL 方向无法解释；替代料没有书面记录；装配预览里出现 J3/J5；发现桥连或电源对地近似短路；电极连接时需要插拔 USB。

## 11. 最终清单：勾完再点“提交订单”

勾选状态只保存在当前浏览器，方便你分阶段下单；不上传任何数据。

我上传的是 heart_v2_fab_revA.zip，不是整个工程目录。 PCB 页面识别为 4 层、约 100 × 32 mm、板厚 0.8 mm。 我确认了 ENIG 是否可用于当前 PCBA 工艺；不可选时已咨询工程。 我上传的是 heart_v2_bom.csv，没有误传 BOM all。 我上传的是 heart_v2_cpl.csv，CPL 全部 top，152 个参考号。 我确认 J3、J5、TP1-TP6 不在 BOM/CPL，但它们的铜接触/测试焊盘仍在 Gerber。 我逐条审核 Manufacturer、MPN、封装、库存和替代料。 我对照顶层 PDF 检查了 U1/U2/U3、二极管、LED、晶振、连接器和天线方向。 我确认没有被自动加入 DNP，且没有误选底面贴片。 我已保存最终匹配表、装配预览、工艺参数、订单号和工程备注。 收板计划包含显微镜检查、限流上电、SWD/USB/SD、RF 和 ECG 模拟器测试。 我理解这不是医疗器械；电极连接时不会插 USB。

已完成 0 / 12 项

## 官方资料与项目资料

嘉立创网页会更新，以下链接用于核对字段、能力和下单流程；页面中的实时限制优先于本教程：

- 嘉立创：从 KiCad 生成 BOM 与坐标文件 (https://jlcpcb.com/help/article/how-to-generate-the-bom-and-centroid-file-from-kicad)
- 嘉立创：PCBA 元件匹配指南 (https://jlcpcb.com/help/article/component-matching-guidelines-for-pcba-orders)
- 嘉立创：PCB Assembly capabilities (https://jlcpcb.com/capabilities/pcb-assembly-capabilities)
- 嘉立创：PCBA FAQ / 下单流程 (https://jlcpcb.com/help/article/pcb-assembly-faqs)
- 嘉立创：Pick-and-Place 文件要求 (https://jlcpcb.com/help/article/pick-place-file-for-pcb-assembly)
- 嘉立创：装配服务条款与来料/方向说明 (https://jlcpcb.com/help/article/terms-and-conditions-of-jlcpcb-assembly-service)
- 本项目 Heart V2 Rev A 审计报告 · 生产包说明

官方页面访问时间：2026-08-26。报价、库存、税费、交期和可选工艺可能变化；提交订单前以嘉立创订单页面和工程确认结果为准。

Heart V2 Rev A · 本页用于工程下单和首板验证记录 · 不是医疗安全说明书

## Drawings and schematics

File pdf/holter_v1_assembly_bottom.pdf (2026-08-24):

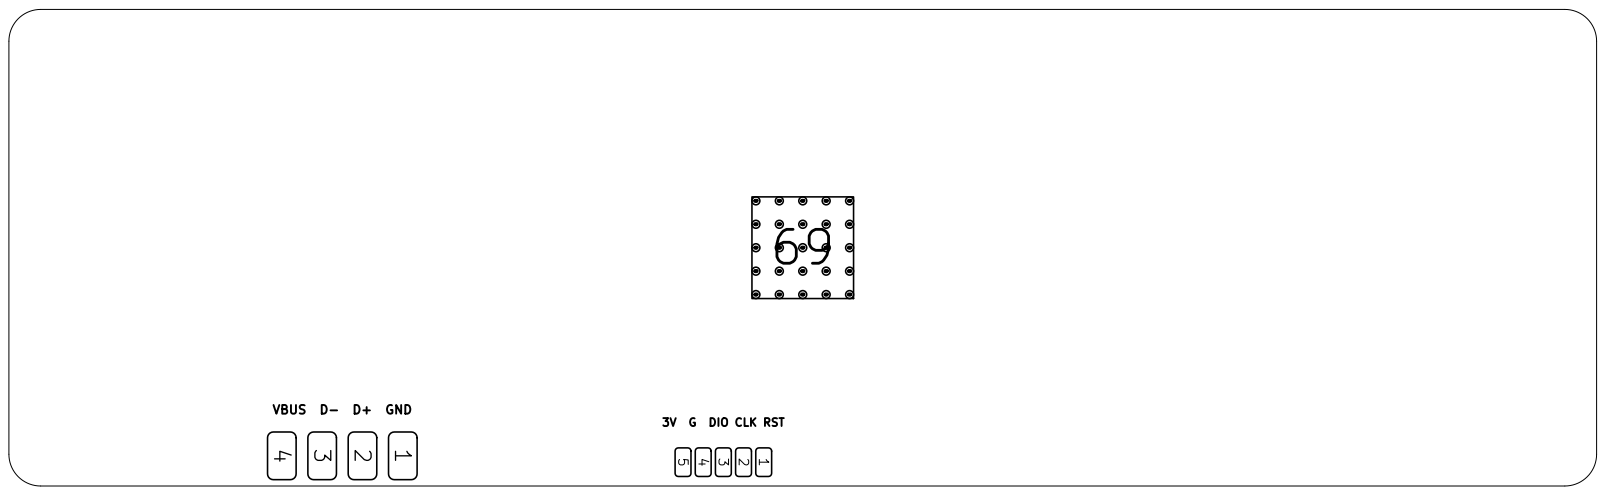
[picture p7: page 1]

3V G DIO CLK RST VBUS D- D+ GND

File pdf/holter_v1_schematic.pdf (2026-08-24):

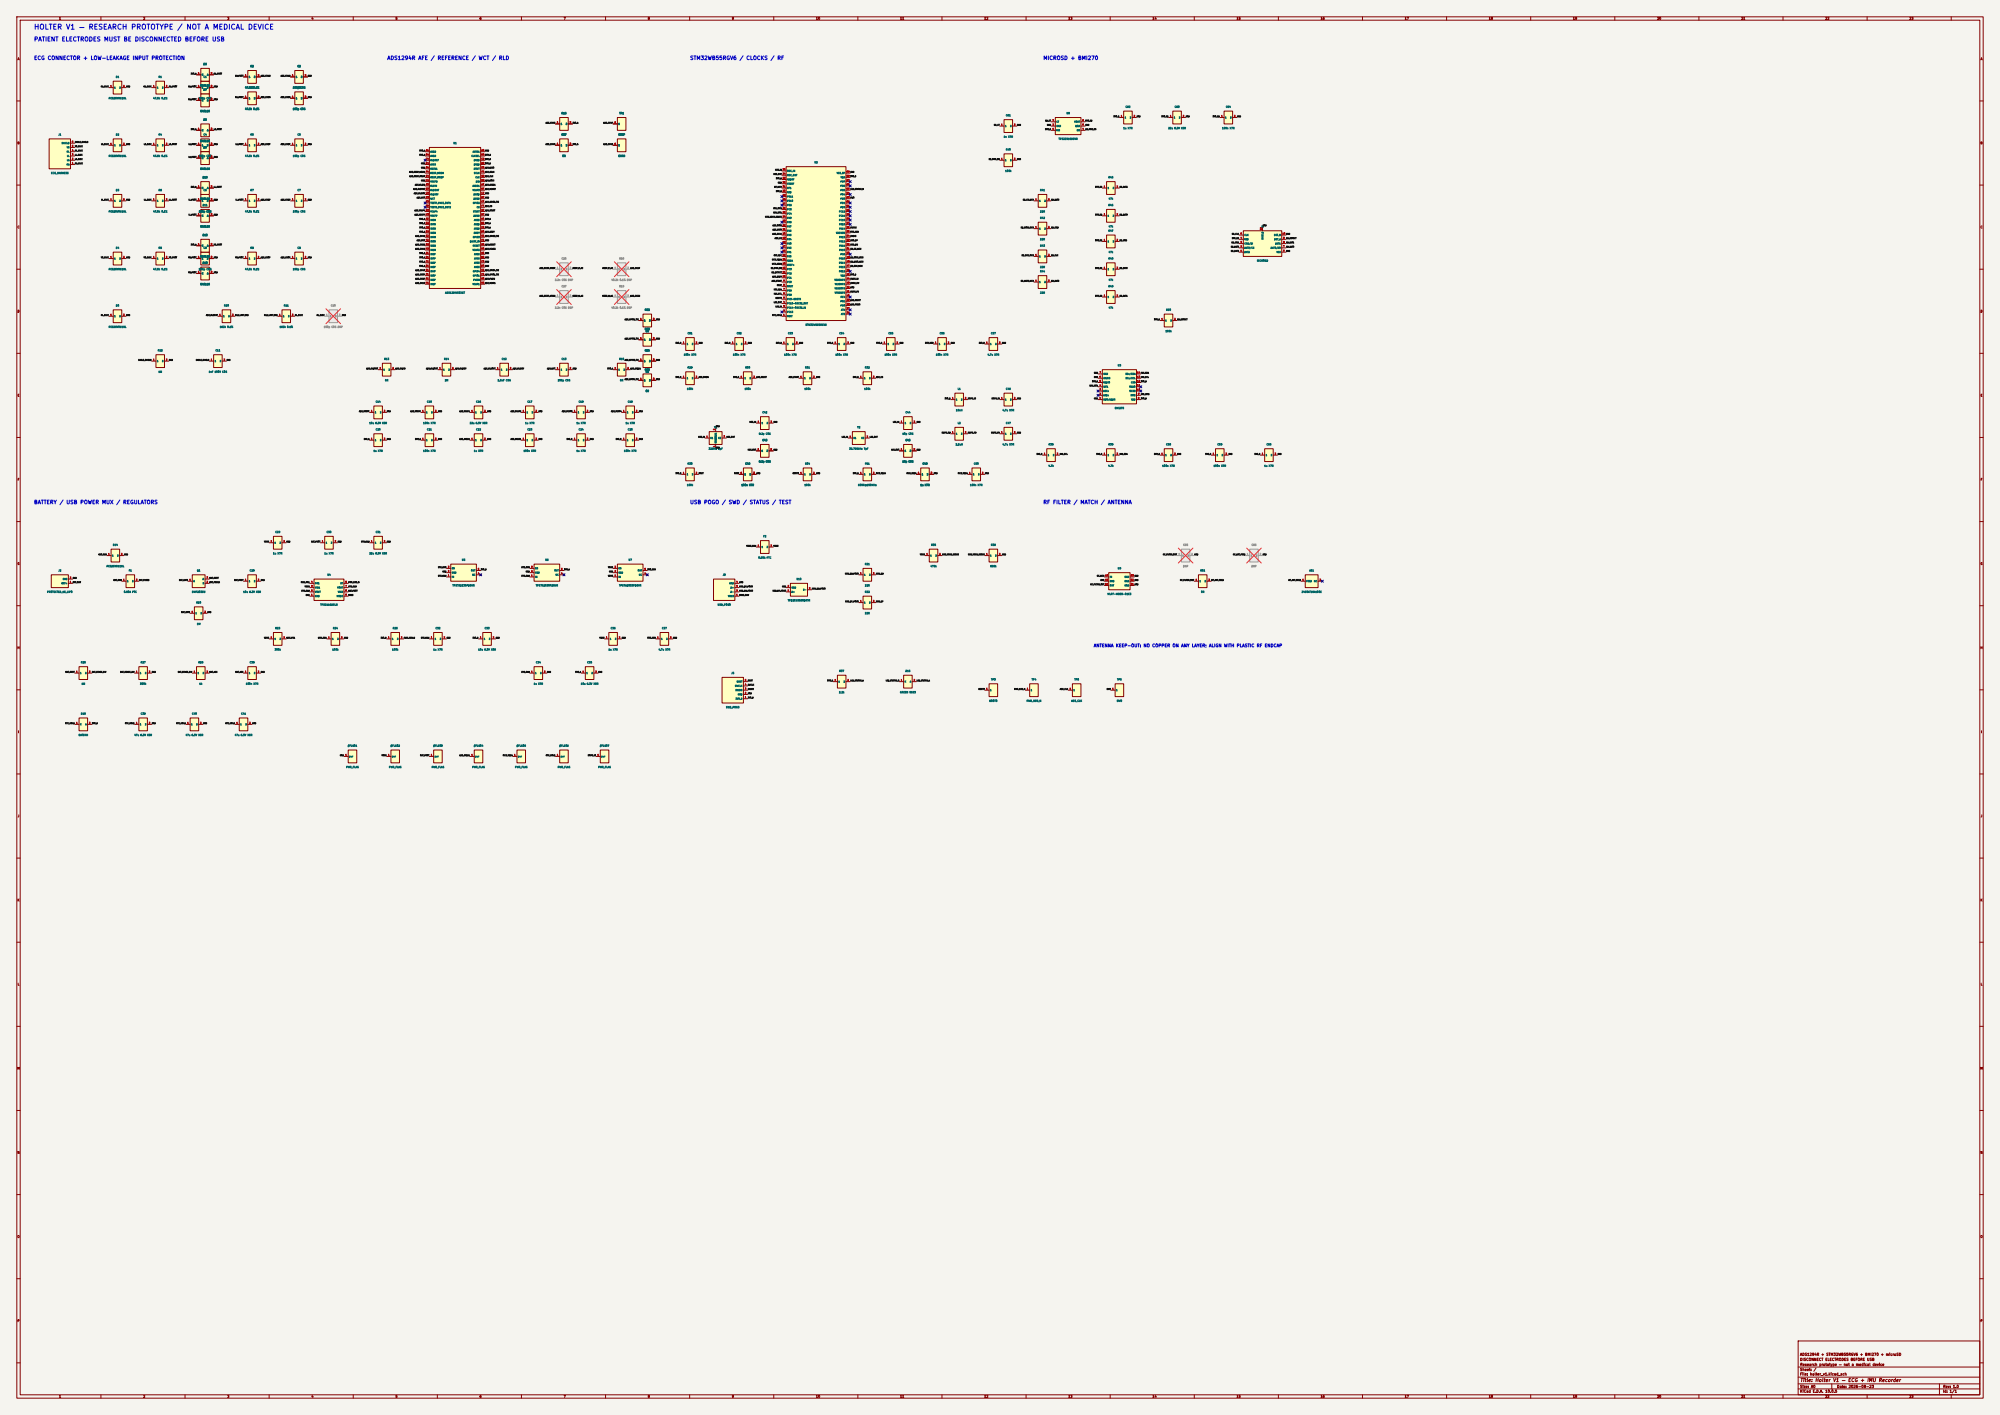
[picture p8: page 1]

HOLTER V1 — RESEARCH PROTOTYPE / NOT A MEDICAL DEVICE

PATIENT ELECTRODES MUST BE DISCONNECTED BEFORE USB

ADS1294R AFE / REFERENCE / WCT / RLD

BATTERY / USB POWER MUX / REGULATORS

USB POGO / SWD / STATUS / TEST

RF FILTER / MATCH / ANTENNA

ANTENNA KEEP-OUT: NO COPPER ON ANY LAYER; ALIGN WITH PLASTIC RF ENDCAP

ADS1294R + STM32WB55RGV6 + BMI270 + microSD
DISCONNECT ELECTRODES BEFORE USB
Research prototype — not a medical device
Sheet: /
File: holter_v1.kicad_sch
Title: Holter V1 — ECG + IMU Recorder

Size: A0 | Rev: 1.0
KiCad E.D.A. 10.0.5 | Id: 1/1

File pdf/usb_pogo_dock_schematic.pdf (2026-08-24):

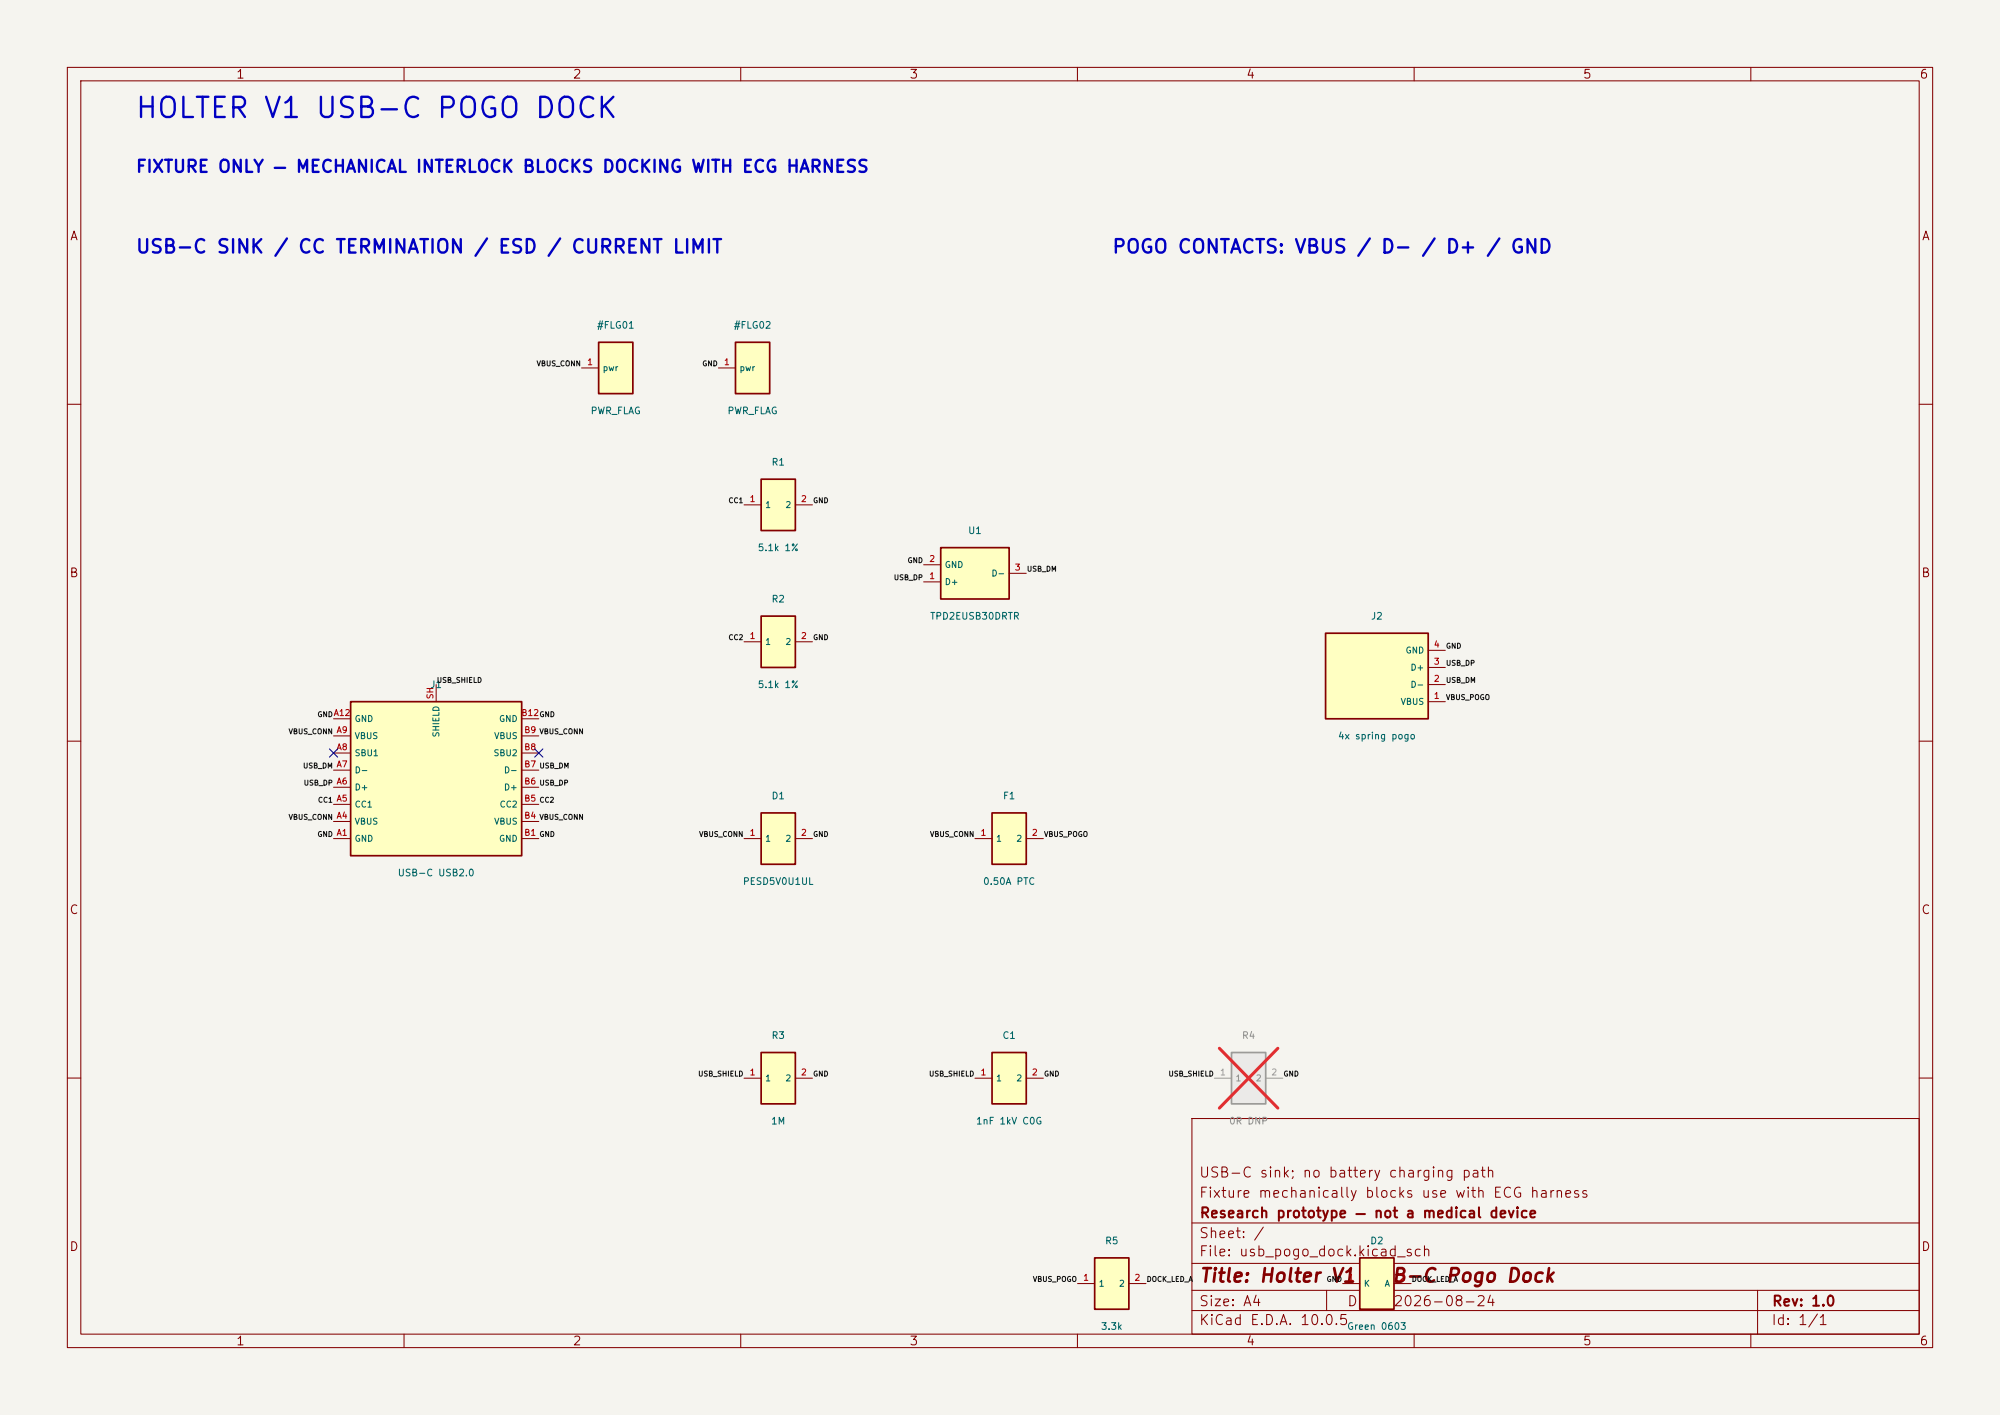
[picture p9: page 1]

GND USB_DM HOLTER V1 USB-C POGO DOCK

FIXTURE ONLY — MECHANICAL INTERLOCK BLOCKS DOCKING WITH ECG HARNESS

USB-C sink; no battery charging path
Fixture mechanically blocks use with ECG harness
Research prototype — not a medical device
Sheet: /
File: usb_pogo_dock.kicad_sch

Title: Holter V1 USB-C Pogo Dock 1 | A | 2 D2 Green 0603

Size: A4 | | | Rev: 1.0
KiCad E.D.A. 10.0.5 | | | Id: 1/1

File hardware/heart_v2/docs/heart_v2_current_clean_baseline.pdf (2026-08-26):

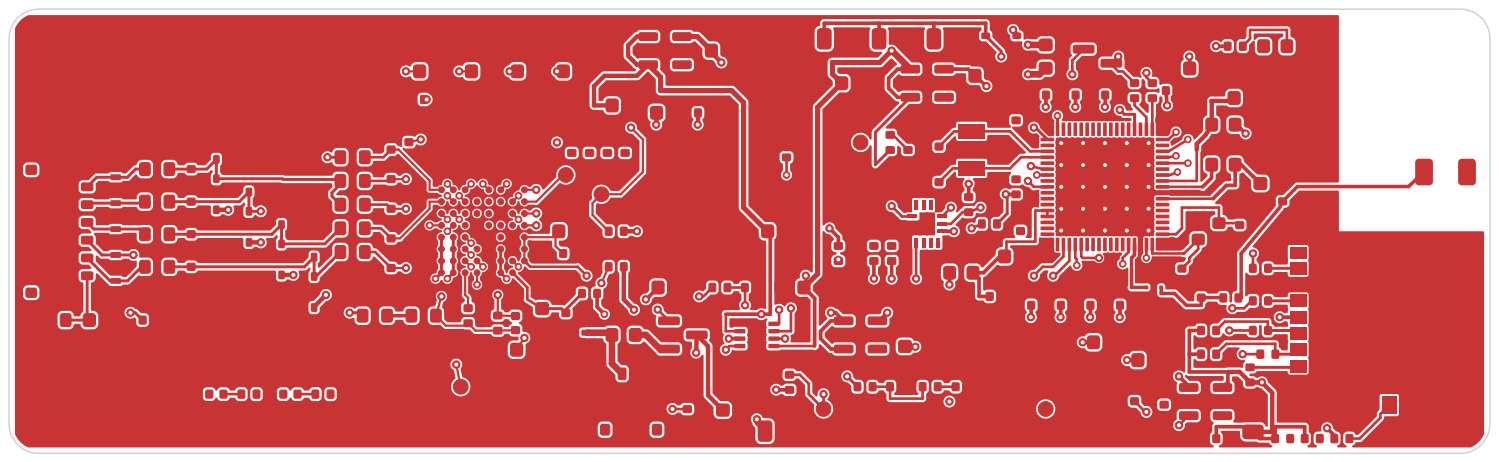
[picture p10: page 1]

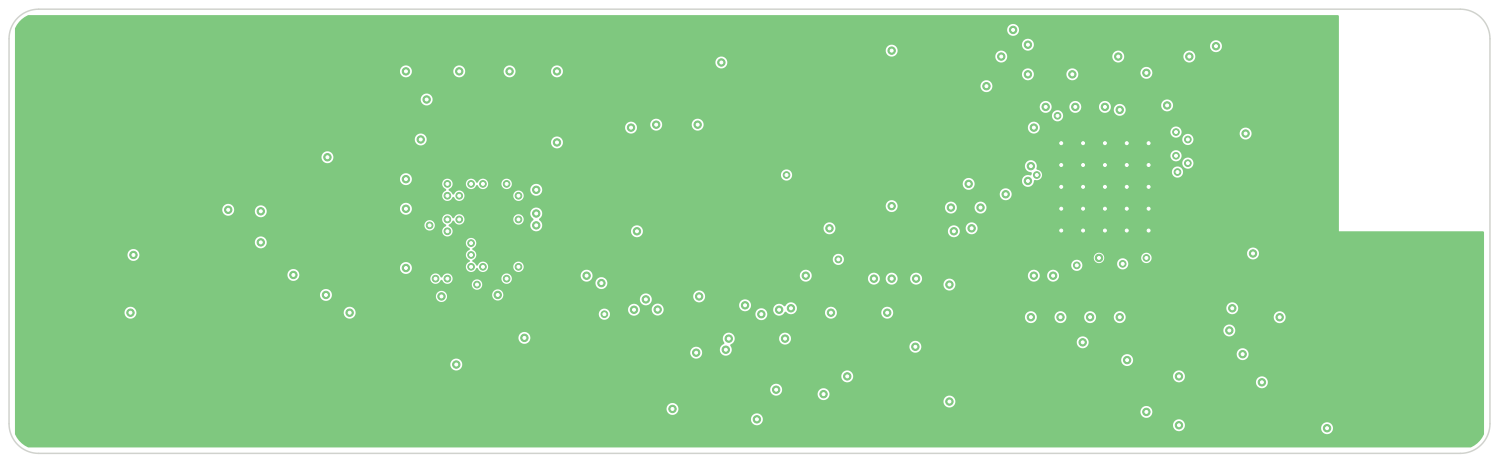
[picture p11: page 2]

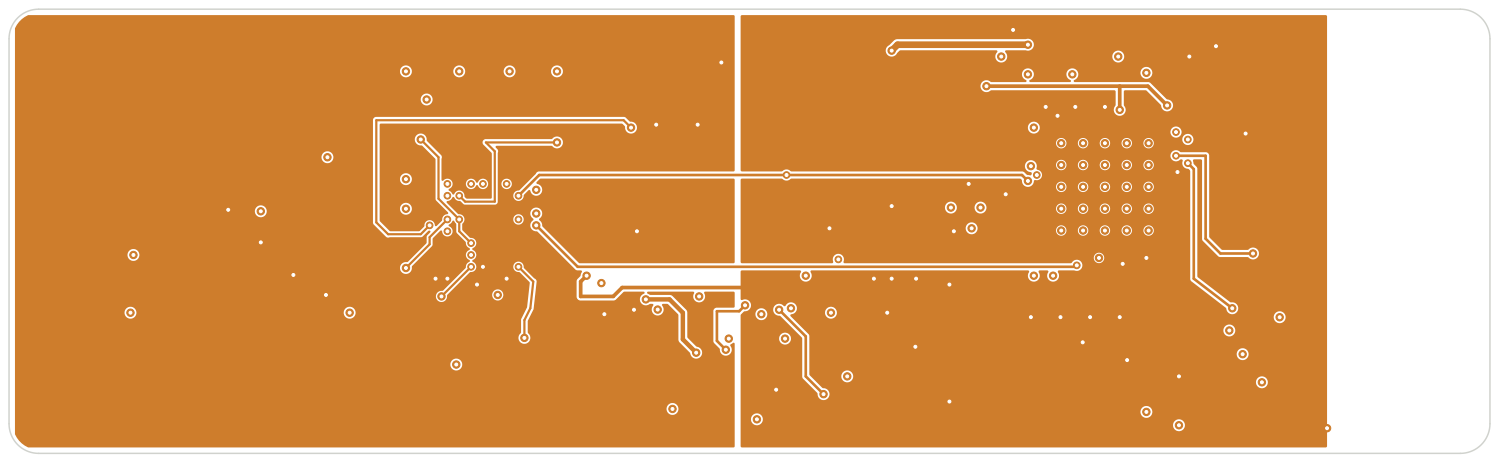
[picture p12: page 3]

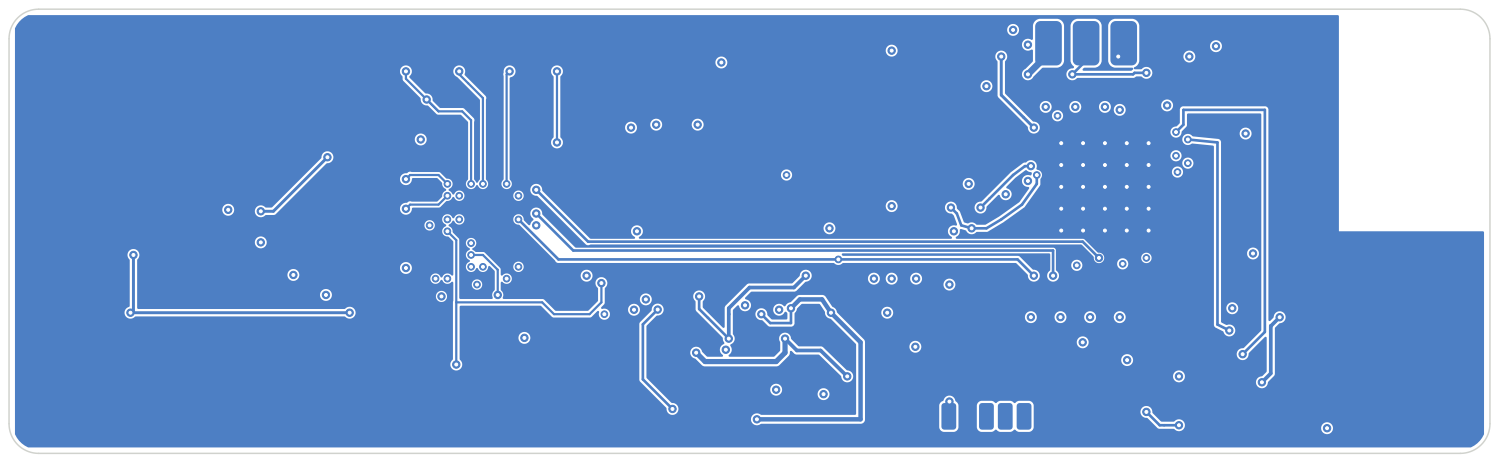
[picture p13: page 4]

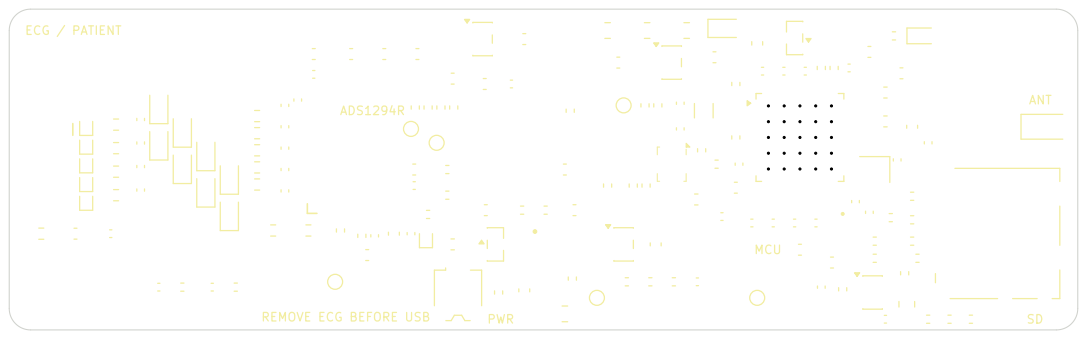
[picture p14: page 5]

REMOVE ECG BEFORE USB

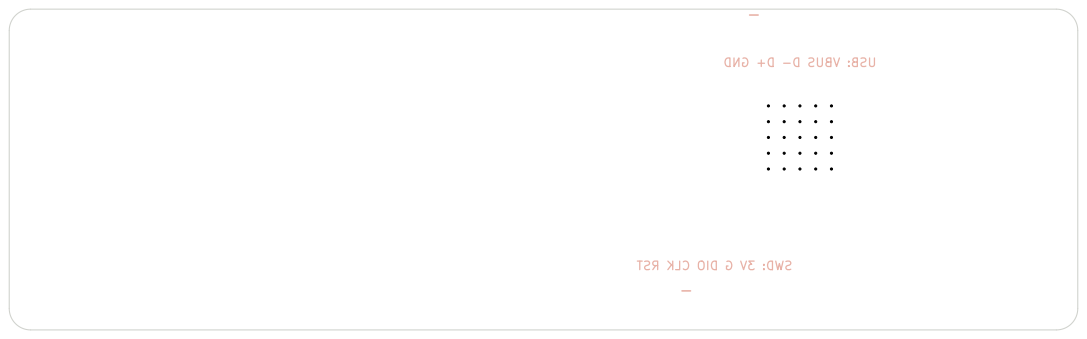
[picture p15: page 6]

RST CLK DIO G 3V SWD:

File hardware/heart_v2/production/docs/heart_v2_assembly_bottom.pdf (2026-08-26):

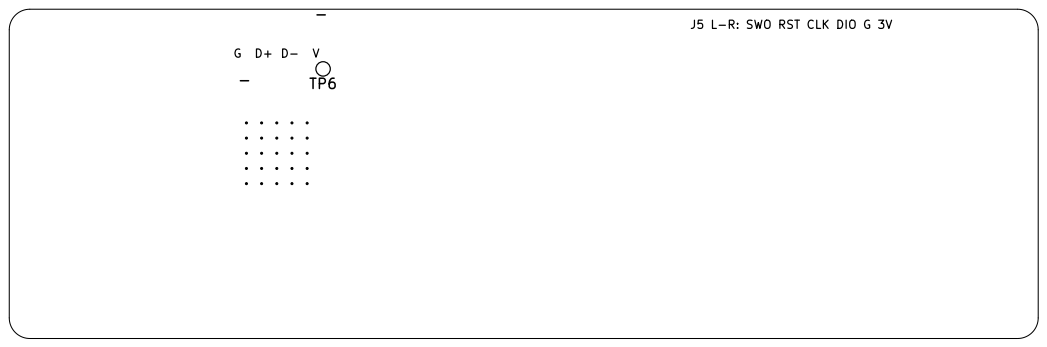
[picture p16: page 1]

J5 L-R: SWO RST CLK DIO G 3V G D+ D- V

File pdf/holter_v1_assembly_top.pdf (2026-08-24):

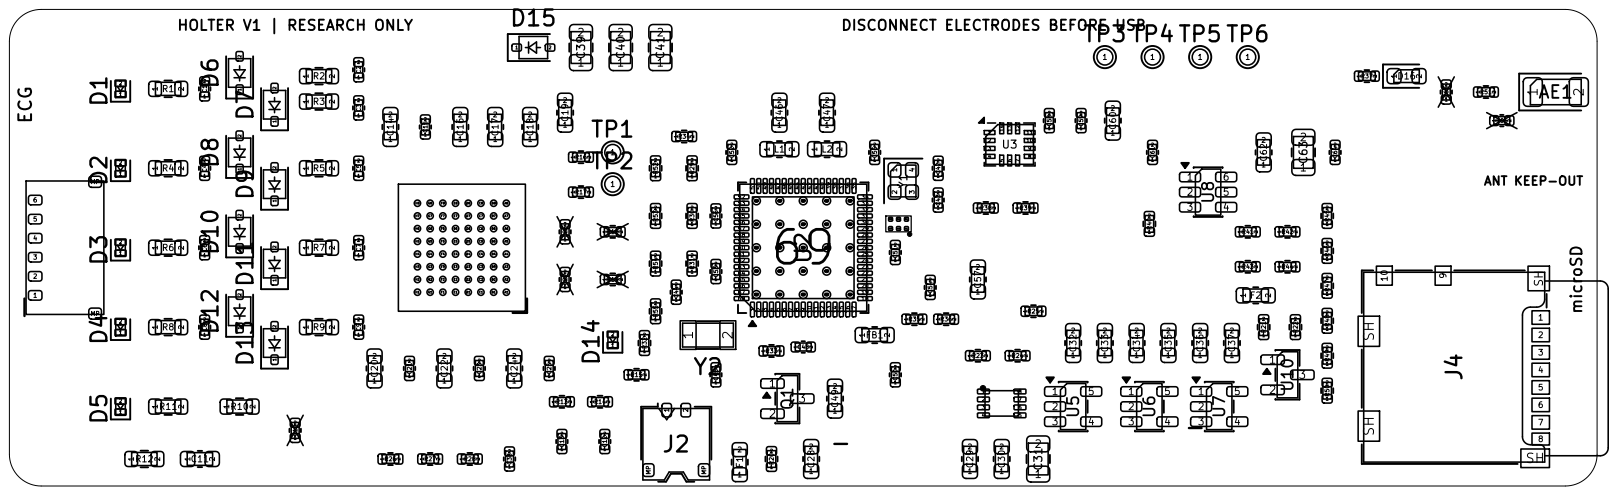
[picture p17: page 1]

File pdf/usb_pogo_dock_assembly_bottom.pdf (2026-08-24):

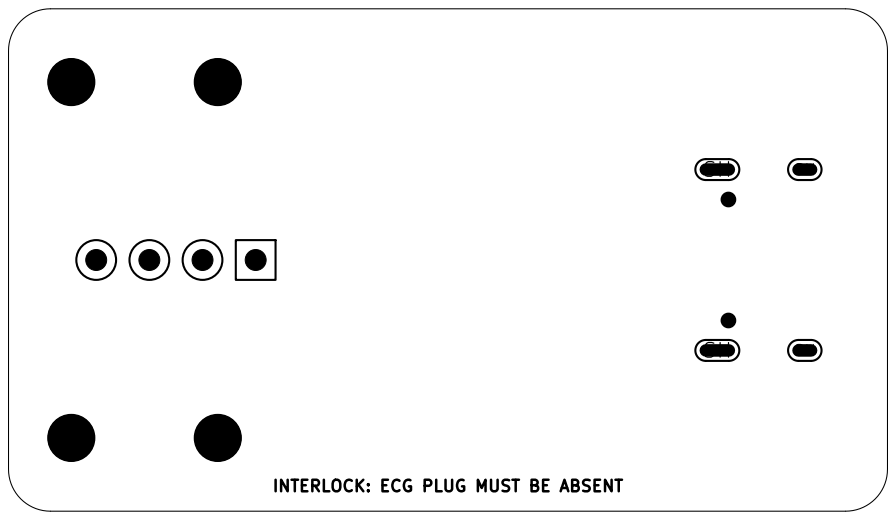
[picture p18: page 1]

INTERLOCK: ECG PLUG MUST BE ABSENT

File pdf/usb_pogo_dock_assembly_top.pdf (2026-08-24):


HOLTER V1 USB POGO DOCK












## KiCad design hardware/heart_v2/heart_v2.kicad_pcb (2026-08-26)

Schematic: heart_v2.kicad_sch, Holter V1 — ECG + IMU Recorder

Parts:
AE1: 2450AT18A100E; Johanson_2450AT18x100_2400-2500Mhz; MPN 2450AT18A100E
C1, C2, C3, C4, C5, C6, C7, C8, C9, C13: 100p C0G; C_0402_1005Metric; MPN GRM1555C1H101JA01D
C10: 100p C0G DNP; C_0402_1005Metric; MPN GRM1555C1H101JA01D; not fitted
C11: 1nF 100V C0G; C_0603_1608Metric; MPN C0603C102J1GACTU
C12: 1.5nF C0G; C_0402_1005Metric; MPN GRM1555C1H152JA01D
C14, C28, C33, C35: 10u 6.3V X5R; C_0603_1608Metric; MPN GRM188R60J106ME47D
C15, C21, C23, C25, C38, C48, C50, C51, C52, C53, C54, C55, C56, C58, C59, C64: 100n X7R; C_0402_1005Metric; MPN GRM155R71C104KA88D
C16: 22u 6.3V X5R; C_0603_1608Metric; MPN GRM188R60J226MEA0D
C17, C18, C19, C20, C22, C24, C29, C30, C32, C34, C36, C49, C60, C62: 1u X7R; C_0603_1608Metric; MPN GRM188R71C105KA12D
C26, C27: 2.2n C0G DNP; C_0402_1005Metric; MPN GRM1555C1H222JA01D; not fitted
C31, C63: 22u 6.3V X5R; C_0805_2012Metric; MPN GRM21BR60J226ME39L
C37, C46, C47, C57: 4.7u X7R; C_0603_1608Metric; MPN GRM188Z71A475KE15D
C39, C40, C41: 47u 6.3V X5R; C_0805_2012Metric; MPN GRM21BR60J476ME15L
C42, C43: 8.2p C0G; C_0402_1005Metric; MPN GRM1555C1H8R2CA01D
C44, C45: 10p C0G; C_0402_1005Metric; MPN GRM1555C1H100JA01D
C61: 1n X7R; C_0402_1005Metric; MPN GRM155R71H102KA01D
C65, C66: DNP; C_0402_1005Metric; not fitted
D1, D2, D3, D4, D5, D14: PESD5V0U1UL; D_SOD-882; MPN PESD5V0U1UL,315
D6, D7, D8, D9, D10, D11, D12, D13: BAS116; D_SOD-323; MPN BAS116,115
D15: BAT54H; D_SOD-323; MPN BAT54H,115
D16: GREEN 0603; LED_0603_1608Metric; MPN 150060VS75000
F1, F2: 0.50A PTC; Fuse_0603_1608Metric; MPN MF-FSMF050X-2
FB1: 600R@100MHz; L_0603_1608Metric; MPN BLM15AG601SN1D
J1: ECG_HARNESS; Molex_Pico-EZmate_78171-5006; MPN 78171-5006
J2: PROTECTED_1S_LIPO; Molex_Pico-EZmate_78171-0002_1x02-1MP_P1.20mm_Vertical; MPN 78171-0002
J3: USB_POGO; Pogo_USB_4x1_P2.54_Bottom
J4: MICROSD; microSD_HC_Molex_104031-0811; MPN 104031-0811
J5: SWD_POGO; Pogo_SWD_5x1_P1.27_Bottom
L1: 10nH; L_0603_1608Metric; MPN LQG15HN10NJ02D
L2: 2.2uH; L_0603_1608Metric; MPN LQM18PN2R2MFRL
Q1: DMP2035U; SOT-23; MPN DMP2035U-7
R1, R2, R3, R4, R5, R6, R7, R8, R9: 47.5k 0.1%; R_0603_1608Metric; MPN RT0603BRD0747K5L
R10, R11: 162k 0.1%; R_0603_1608Metric; MPN RT0603BRD07162KL
R12: 1M; R_0603_1608Metric; MPN RC0603FR-071ML
R13, R15, R16, R17, R51, R52, R53, R54, R55: 0R; R_0402_1005Metric; MPN RC0402JR-070RL
R14, R20, R26: 1M; R_0402_1005Metric; MPN RC0402FR-071ML
R18, R19: 40.2k 0.1% DNP; R_0402_1005Metric; MPN RT0402BRD0740K2L; not fitted
R21, R22, R41, R42, R43, R44: 22R; R_0402_1005Metric; MPN RC0402FR-0722RL
R23: 300k; R_0402_1005Metric; MPN RC0402FR-07300KL
R24, R25, R29, R30, R31, R32, R33, R34, R40, R50: 100k; R_0402_1005Metric; MPN RC0402FR-07100KL
R27: 330k; R_0402_1005Metric; MPN RC0402FR-07330KL
R28: 1k; R_0402_1005Metric; MPN RC0402FR-071KL
R35: 470k; R_0402_1005Metric; MPN RC0402FR-07470KL
R36: 680k; R_0402_1005Metric; MPN RC0402FR-07680KL
R37: 2.2k; R_0402_1005Metric; MPN RC0402FR-072K2L
R38, R39: 4.7k; R_0402_1005Metric; MPN RC0402FR-074K7L
R45, R46, R47, R48, R49: 47k; R_0402_1005Metric; MPN RC0402FR-0747KL
TP1: CH4P; TestPoint_Pad_D1.0mm
TP2: CH4N; TestPoint_Pad_D1.0mm
TP3: BOOT0; TestPoint_Pad_D1.0mm
TP4: PWR_USB_N; TestPoint_Pad_D1.0mm
TP5: ADS_CLK; TestPoint_Pad_D1.0mm
TP6: SWO; TestPoint_Pad_D1.0mm
U1: ADS1294RIZXGT; ADS1294R_ZXG; MPN ADS1294RIZXGT
U2: STM32WB55RGV6; QFN-68-1EP_8x8mm_P0.4mm_EP6.4x6.4mm_ThermalVias; MPN STM32WB55RGV6
U3: BMI270; Bosch_LGA-14_3x2.5mm_P0.5mm; MPN BMI270
U4: TPS2116DRLR; Texas_DRL0008A; MPN TPS2116DRLR
U5: TPS7A2130PDBVR; SOT-23-5; MPN TPS7A2130PDBVR
U6: TPS7A2030PDBVR; SOT-23-5; MPN TPS7A2030PDBVR
U7: TPS7A2033PDBVR; SOT-23-5; MPN TPS7A2033PDBVR
U8: TPS22918DBVR; SOT-23-6; MPN TPS22918DBVR
U9: MLPF-WB55-01E3; MPN MLPF-WB55-01E3
U10: TPD2EUSB30DRTR; SOT-23; MPN TPD2EUSB30DRTR
Y1: 32MHz 6pF; Crystal_SMD_2016-4Pin_2.0x1.6mm; MPN NX2016SA-32M-EXS00A-CS06465
Y2: 32.768kHz 7pF; Crystal_SMD_3215-2Pin_3.2x1.5mm; MPN NX3215SA-32.768K-STD-MUA-14

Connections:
/3V0_A: C20.1, C21.1, C35.1, D6.1 (K), D8.1 (K), D10.1 (K), D12.1 (K), R15.1, R16.2, R17.2, U1.A1 (IN8P), U1.A2 (IN8N), U1.A4 (AVDD), U1.A6 (AVDD), U1.B1 (IN7P), U1.B2 (IN7N), U1.B4 (AVDD), U1.B6 (AVDD), U1.C1 (IN6P), U1.C2 (IN6N), U1.C6 (AVDD), U1.D1 (IN5P), U1.D2 (IN5N), U6.5 (OUT)
/3V0_D: C24.1, C25.1, C33.1, C51.1, C52.1, C53.1, C54.1, C55.1, C57.1, C58.1, C59.1, C60.1, C62.1, D15.2 (A), FB1.1, J5.1 (3V0_D), L1.1, R25.1, R29.1, R30.1, R32.1, R33.1, R37.1, R38.1, R39.1, R50.1, U1.B8 (CLKSEL), U1.C8 (DVDD), U1.D8 (DVDD), U2.30 (VDD), U2.33 (VDDRF), U2.45 (VDD), U2.68 (VDD), U3.5 (VDDIO), U3.8 (VDD), U3.12 (CSB), U5.5 (OUT), U8.1 (VIN)
/3V0_SD: C63.1, C64.1, J4.4 (VDD), R45.1, R46.1, R47.1, R48.1, R49.1, U8.6 (VOUT)
/3V3_USB: C37.1, C56.1, U2.55 (VDDUSB), U7.5 (OUT)
/ADS_AVDD1: C22.1, C23.1, R15.2, U1.A7 (AVDD1)
/ADS_CH1N: C2.1, R2.2, U1.H2 (IN1N)
/ADS_CH1P: C5.1, R5.2, U1.H1 (IN1P)
/ADS_CH2N: C3.1, R3.2, R19.2, U1.G2 (IN2N)
/ADS_CH2P: C7.1, R7.2, R18.2, U1.G1 (IN2P)
/ADS_CH3P: C9.1, R9.2, U1.F1 (IN3P)
/ADS_CH4N: R17.1, TP2.1 (1_1), U1.E2 (IN4N)
/ADS_CH4P: R16.1, TP1.1 (1_1), U1.E1 (IN4P)
/ADS_CLK: TP5.1 (1_1), U1.G8 (CLK)
/ADS_CS: R32.2, U1.F7 (CS), U2.19 (PA4)
/ADS_DRDY: U1.D6 (DRDY), U2.10 (PC1)
/ADS_GPIO1_TIE: R52.1, U1.F5 (GPIO1)
/ADS_GPIO2_TIE: R53.1, U1.E7 (GPIO2)
/ADS_GPIO3_TIE: R54.1, U1.E6 (GPIO3)
/ADS_GPIO4_TIE: R55.1, U1.E5 (GPIO4)
/ADS_MISO: U1.E8 (DOUT), U2.21 (PA6)
/ADS_MOSI: U1.H8 (DIN), U2.22 (PA7)
/ADS_PWDN: R29.2, U1.G5 (PWDN), U2.38 (PB0)
/ADS_RESET: R30.2, U1.G6 (RESET), U2.39 (PB1)
/ADS_RESP_MODN: C27.1, U1.F4 (RESP_MODN)
/ADS_RESP_MODP: C26.1, U1.G4 (RESP_MODP)
/ADS_RLDIN: R13.2, U1.A3 (RLDIN)
/ADS_RLDINV: C12.2, R14.2, U1.C3 (RLDINV)
/ADS_RLDOUT: C12.1, R10.1, R13.1, R14.1, U1.B3 (RLDOUT)
/ADS_SCLK: U1.F8 (SCLK), U2.20 (PA5)
/ADS_START: R31.1, U1.G7 (START), U2.9 (PC0)
/ADS_VCAP1: C16.1, U1.H5 (VCAP1)
/ADS_VCAP2: C17.1, U1.H6 (VCAP2)
/ADS_VCAP3: C18.1, U1.B7 (VCAP3)
/ADS_VCAP4: C19.1, U1.G3 (VCAP4)
/ADS_VREFP: C14.1, C15.1, U1.H3 (VREFP)
/ADS_WCT: C13.1, U1.D3 (WCT), U1.F2 (IN3N)
/BAT_ADC: C38.1, R28.2, U2.15 (PA0)
/BAT_FUSED: F1.2, Q1.2 (S)
/BAT_GATE: Q1.1 (G), R20.1
/BAT_PROT: C28.1, C30.1, Q1.3 (D), R26.1, U4.6 (VIN2)
/BAT_RAW: D14.1, F1.1, J2.1 (BAT+)
/BAT_SENSE_DIV: R26.2, R27.1, R28.1
/BOOT0: R34.1, TP3.1 (1_1), U2.5 (PH3-BOOT0)
/CABLE_SHIELD: C11.1, J1.6 (SHIELD), R12.1
/GND: C1.2, C2.2, C3.2, C4.2, C5.2, C6.2, C7.2, C8.2, C9.2, C10.2, C11.2, C13.2, C14.2, C15.2, C16.2, C17.2, C18.2, C19.2, C20.2, C21.2, C22.2, C23.2, C24.2, C25.2, C28.2, C29.2, C30.2, C31.2, C32.2, C33.2, C34.2, C35.2, C36.2, C37.2, C38.2, C39.2, C40.2, C41.2, C42.2, C43.2, C44.2, C45.2, C46.2, C47.2, C48.2, C49.2, C50.2, C51.2, C52.2, C53.2, C54.2, C55.2, C56.2, C57.2, C58.2, C59.2, C60.2, C61.2, C62.2, C63.2, C64.2, C65.2, C66.2, D1.2, D2.2, D3.2, D4.2, D5.2, D7.2 (A), D9.2 (A), D11.2 (A), D13.2 (A), D14.2, J2.2 (GND), J3.4 (GND), J4.6 (VSS), J4.10 (DET_B), J4.SH (SHIELD), J5.2 (GND), R12.2, R20.2, R24.2, R27.2, R31.2, R34.2, R36.2, R40.2, R52.2, R53.2, R54.2, R55.2, U1.A5 (AVSS), U1.A8 (AVSS1), U1.B5 (AVSS), U1.C5 (AVSS), U1.C7 (DGND), U1.D4 (AVSS), U1.D5 (AVSS), U1.D7 (DGND), U1.E4 (RESV1), U1.F6 (DAISY_IN), U1.H4 (VREFN), U1.H7 (DGND), U2.32 (VSSRF), U2.42 (VSSSMPS), U2.69 (VSS_EP), U3.1 (SDO/ADDR), U3.6 (GNDIO), U3.7 (GND), U4.1 (GND), U5.2 (GND), U6.2 (GND), U7.2 (GND), U8.2 (GND), U8.5 (QOD), U9.A2 (GND), U9.B1 (GND), U9.B2 (GND), U9.B3 (GND), U10.2 (GND), Y1.2 (GND1), Y1.4 (GND2)
/HSE_IN: C42.1, U2.35 (OSC_IN), Y1.1 (X1)
/HSE_OUT: C43.1, U2.34 (OSC_OUT), Y1.3 (X2)
/IMU_INT1: U2.25 (PC4), U3.4 (INT1)
/IMU_INT2: U2.26 (PC5), U3.9 (INT2)
/IMU_SCL: R38.2, U2.6 (PB8), U3.13 (SCx/SCL)
/IMU_SDA: R39.2, U2.7 (PB9), U3.14 (SDx/SDA)
/LA_ELEC: D2.1, J1.2 (LA), R4.1
/LA_PROT: C4.1, D8.2 (A), D9.1 (K), R4.2, R5.1
/LED_STATUS_A: D16.2 (A), R37.2
/LED_STATUS_N: D16.1 (K), U2.65 (PB5)
/LL_ELEC: D3.1, J1.3 (LL), R6.1
/LL_PROT: C6.1, D10.2 (A), D11.1 (K), R6.2, R7.1
/LSE_IN: C44.1, U2.3 (PC14-OSC32_IN), Y2.1 (X1)
/LSE_OUT: C45.1, U2.4 (PC15-OSC32_OUT), Y2.2 (X2)
/MCU_VDDA: C49.1, C50.1, FB1.2, U2.13 (VREF+), U2.14 (VDDA)
/MUX_PR1: R23.2, R24.1, U4.4 (PR1)
/NRST: C48.1, J5.5 (NRST), R33.2, U2.8 (NRST)
/PWR_USB_N: R25.2, TP4.1 (1_1), U4.8 (ST)
/RA_ELEC: D1.1, J1.1 (RA), R1.1
/RA_PROT: C1.1, D6.2 (A), D7.1 (K), R1.2, R2.1, R3.1
/RESP_N_AC: C27.2, R19.1
/RESP_P_AC: C26.2, R18.1
/RF_ANT_FEED: AE1.1 (FEED_1), C66.1, R51.2
/RF_FILTER_OUT: C65.1, R51.1, U9.A1 (OUT)
/RF_MCU: U2.31 (RF1), U9.A3 (IN)
/RLD_LIMIT_MID: R10.2, R11.1
/RL_ELEC: C10.1, D5.1, J1.4 (RL), R11.2
/RTC_HOLD: C39.1, C40.1, C41.1, D15.1 (K), U2.1 (VBAT)
/SD_CLK: J4.5 (CLK), R43.2
/SD_CMD: J4.3 (CMD/DI), R42.2, R47.2
/SD_CS_MCU: R41.1, U2.51 (PA10)
/SD_CT: C61.1, U8.3 (CT)
/SD_DAT0: J4.7 (DAT0/DO), R44.2, R48.2
/SD_DAT1: J4.8 (DAT1), R49.2
/SD_DAT2: J4.1 (DAT2), R45.2
/SD_DAT3: J4.2 (DAT3/CS), R41.2, R46.2
/SD_DETECT: J4.9 (DET_A), R50.2, U2.11 (PC2)
/SD_MISO_MCU: R44.1, U2.48 (PB14)
/SD_MOSI_MCU: R42.1, U2.49 (PB15)
/SD_PWR_EN: R40.1, U2.12 (PC3), U8.4 (ON)
/SD_SCK_MCU: R43.1, U2.47 (PB13)
/SMPS_FB: C47.1, L2.2, U2.41 (VFBSMPS)
/SMPS_IN: C46.1, L1.2, U2.44 (VDDSMPS)
/SMPS_SW: L2.1, U2.43 (VLXSMPS)
/SWCLK: J5.4 (SWCLK), U2.56 (PA14)
/SWDIO: J5.3 (SWDIO), U2.54 (PA13)
/SWO: TP6.1 (1_1), U2.63 (PB3)
/SYS_RAW: C31.1, C32.1, C34.1, U4.2 (VOUT), U4.7 (VOUT), U5.1 (IN), U5.3 (EN), U6.1 (IN), U6.3 (EN)
/USB_DM: R21.2, U2.52 (PA11)
/USB_DM_POGO: J3.2 (D-), R21.1, U10.3 (D-)
/USB_DP: R22.2, U2.53 (PA12)
/USB_DP_POGO: J3.3 (D+), R22.1, U10.1 (D+)
/USB_VBUS_SENSE: R35.2, R36.1, U2.24 (PA9)
/V5_ELEC: D4.1, J1.5 (V5), R8.1
/V5_PROT: C8.1, D12.2 (A), D13.1 (K), R8.2, R9.1
/VBUS: C29.1, C36.1, F2.2, R23.1, R35.1, U4.3 (VIN1), U4.5 (MODE), U7.1 (IN), U7.3 (EN)
/VBUS_RAW: F2.1, J3.1 (VBUS)

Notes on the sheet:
HOLTER V1 — RESEARCH PROTOTYPE / NOT A MEDICAL DEVICE
PATIENT ELECTRODES MUST BE DISCONNECTED BEFORE USB
ECG CONNECTOR + LOW-LEAKAGE INPUT PROTECTION
ADS1294R AFE / REFERENCE / WCT / RLD
STM32WB55RGV6 / CLOCKS / RF
MICROSD + BMI270
BATTERY / USB POWER MUX / REGULATORS
USB POGO / SWD / STATUS / TEST
RF FILTER / MATCH / ANTENNA
ANTENNA KEEP-OUT: NO COPPER ON ANY LAYER; ALIGN WITH PLASTIC RF ENDCAP

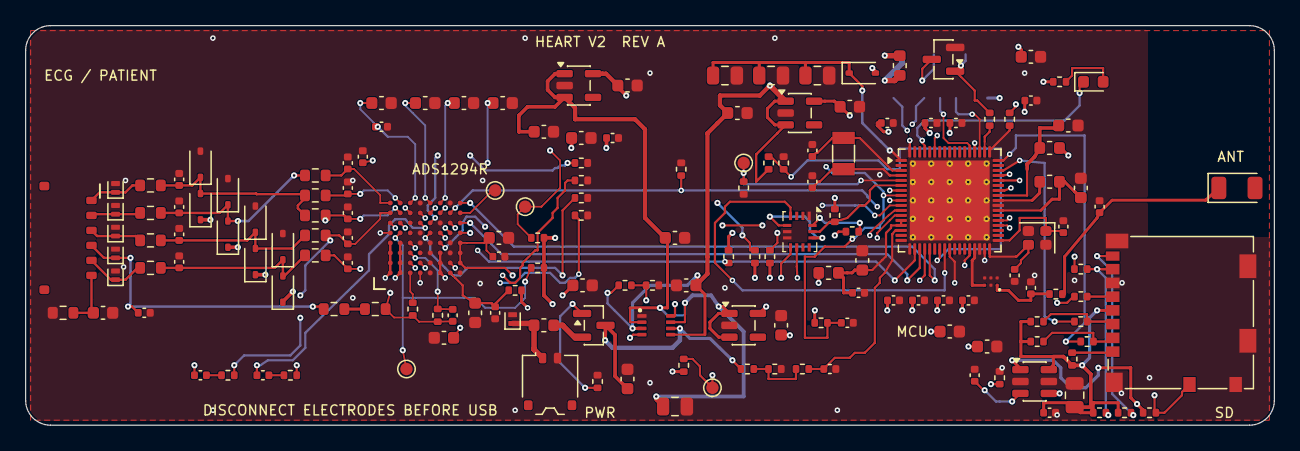
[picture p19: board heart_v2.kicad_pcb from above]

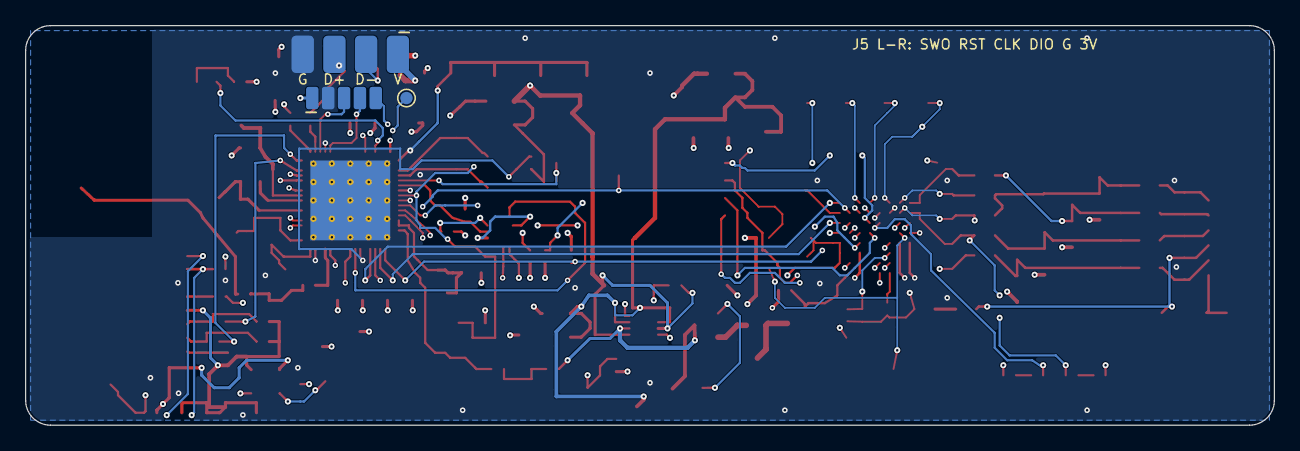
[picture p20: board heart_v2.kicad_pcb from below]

Board: 4 copper layers, 100.0 x 32.0 mm, 167 parts (3 on the bottom side), 102 nets.

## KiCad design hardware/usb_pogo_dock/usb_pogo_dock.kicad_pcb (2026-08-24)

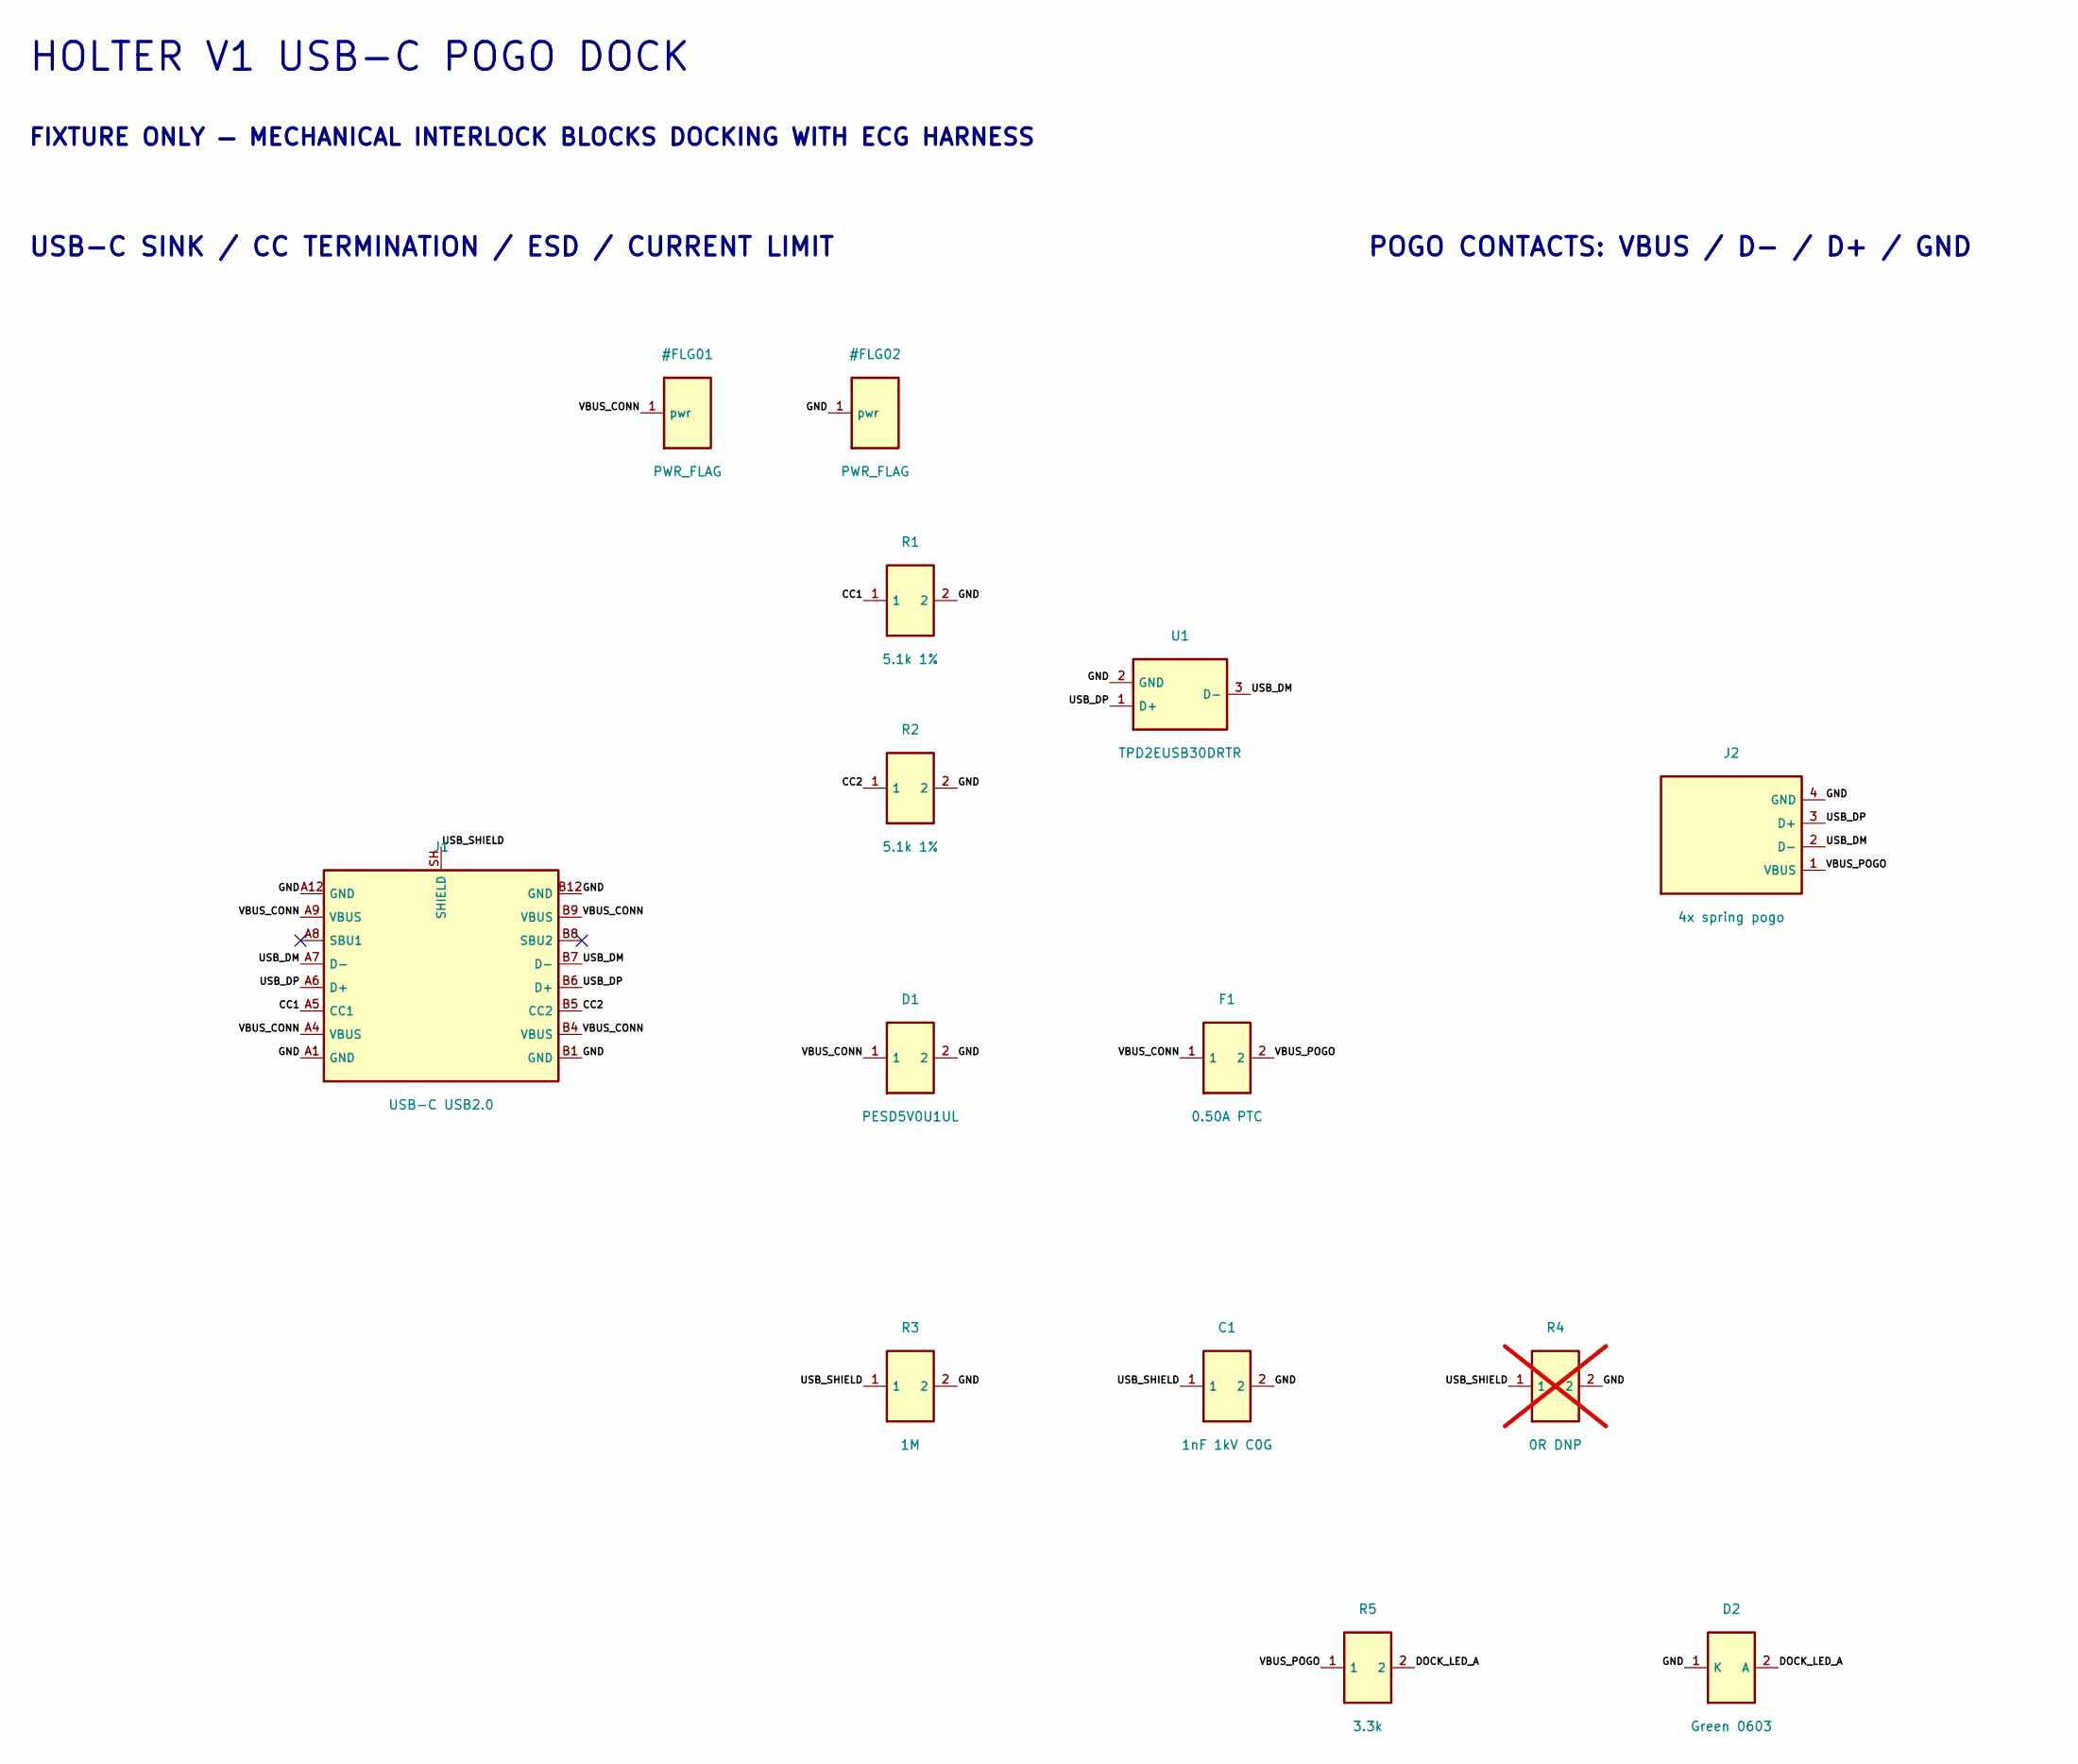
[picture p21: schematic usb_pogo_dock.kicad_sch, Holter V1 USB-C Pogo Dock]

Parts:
C1: 1nF 1kV C0G; C_1206_3216Metric; MPN C1206C102JDGACTU
D1: PESD5V0U1UL; D_SOD-882; MPN PESD5V0U1UL,315
D2: Green 0603; LED_0603_1608Metric; MPN LTST-C190KGKT
F1: 0.50A PTC; Fuse_0603_1608Metric; MPN MF-FSMF050X-2
J1: USB-C USB2.0; USB_C_Receptacle_HRO_TYPE-C-31-M-12; MPN TYPE-C-31-M-12
J2: 4x spring pogo; Pogo_Dock_4x1_P2.54_Top; MPN 0906-series / hand fitted
R1, R2: 5.1k 1%; R_0402_1005Metric; MPN RC0402FR-075K1L
R3: 1M; R_0603_1608Metric; MPN RC0603FR-071ML
R4: 0R DNP; R_0603_1608Metric; MPN RC0603JR-070RL; not fitted
R5: 3.3k; R_0402_1005Metric; MPN RC0402FR-073K3L
U1: TPD2EUSB30DRTR; SOT-23; MPN TPD2EUSB30DRTR

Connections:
CC1: J1.A5 (CC1), R1.1
CC2: J1.B5 (CC2), R2.1
DOCK_LED_A: D2.2 (A), R5.2
GND: C1.2, D1.2, D2.1 (K), J1.A1 (GND), J1.A12 (GND), J1.B1 (GND), J1.B12 (GND), J2.4 (GND), R1.2, R2.2, R3.2, R4.2, U1.2 (GND)
USB_DM: J1.A7 (D-), J1.B7 (D-), J2.2 (D-), U1.3 (D-)
USB_DP: J1.A6 (D+), J1.B6 (D+), J2.3 (D+), U1.1 (D+)
USB_SHIELD: C1.1, J1.SH (SHIELD), R3.1, R4.1
VBUS_CONN: D1.1, F1.1, J1.A4 (VBUS), J1.A9 (VBUS), J1.B4 (VBUS), J1.B9 (VBUS)
VBUS_POGO: F1.2, J2.1 (VBUS), R5.1

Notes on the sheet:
HOLTER V1 USB-C POGO DOCK
FIXTURE ONLY — MECHANICAL INTERLOCK BLOCKS DOCKING WITH ECG HARNESS
USB-C SINK / CC TERMINATION / ESD / CURRENT LIMIT
POGO CONTACTS: VBUS / D- / D+ / GND

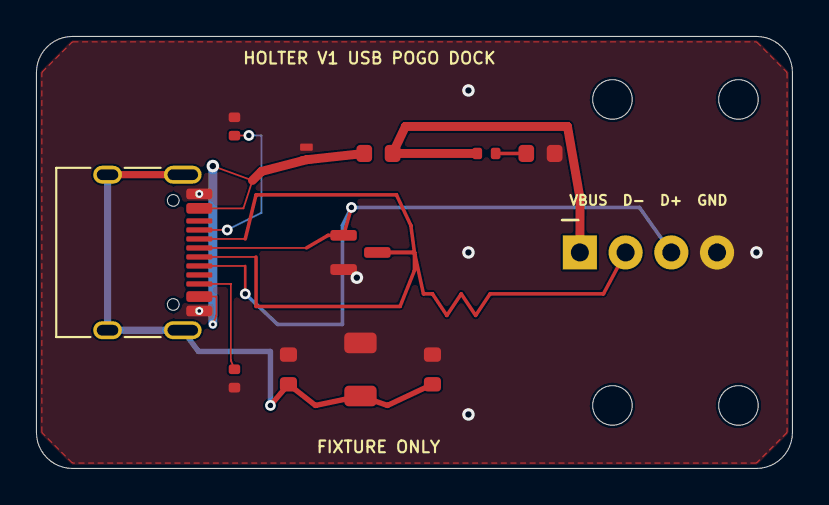
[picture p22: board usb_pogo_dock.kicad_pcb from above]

Board: 2 copper layers, 42.0 x 24.0 mm, 16 parts (0 on the bottom side), 9 nets.

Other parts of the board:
H1, H2, H3, H4: M2 FIXTURE; MountingHole_2.2mm_M2

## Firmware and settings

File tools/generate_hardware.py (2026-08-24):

#!/usr/bin/env python3
"""Generate the deterministic KiCad sources for Holter V1.

The generated schematic deliberately embeds every symbol definition so it can be
opened on a clean KiCad 10 installation.  Run this script with ordinary Python;
PCB generation is kept in a separate script because it uses KiCad's pcbnew API.
"""

from __future__ import annotations

import csv
import json
import math
import re
import uuid
from dataclasses import dataclass, field
from pathlib import Path
from typing import Iterable


ROOT = Path(__file__).resolve().parents[1]
HW = ROOT / "hardware" / "holter_v1"
LIB = HW / "libraries"
PRETTY = LIB / "holter_v1.pretty"
DOCS = ROOT / "docs"

UUID_NS = uuid.UUID("a5ad17c2-0694-55d5-8bc1-97924848f49c")


def uid(key: str) -> str:
    return str(uuid.uuid5(UUID_NS, key))


def q(value: object) -> str:
    text = str(value)
    text = text.replace("\\", "\\\\").replace('"', '\\"')
    return f'"{text}"'


def fmt(value: float) -> str:
    if abs(value - round(value)) < 1e-9:
        return str(int(round(value)))
    return f"{value:.4f}".rstrip("0").rstrip(".")


@dataclass(frozen=True)
class Pin:
    number: str
    name: str
    etype: str = "passive"
    side: str = "left"


@dataclass
class SymbolType:
    name: str
    reference: str
    pins: list[Pin]
    description: str
    width: float = 20.32
    pin_pitch: float = 2.54
    pin_xy: dict[str, tuple[float, float, str]] = field(default_factory=dict)

    def calculate_geometry(self) -> None:
        groups = {
            side: [pin for pin in self.pins if pin.side == side]
            for side in ("left", "right", "top", "bottom")
        }
        rows = max(len(groups["left"]), len(groups["right"]), 2)
        height = max(7.62, (rows + 1) * self.pin_pitch)
        x_body = self.width / 2
        y_top = -height / 2
        y_bottom = height / 2

        for side in ("left", "right"):
            pins = groups[side]
            for index, pin in enumerate(pins):
                y = (index - (len(pins) - 1) / 2) * self.pin_pitch
                if side == "left":
                    self.pin_xy[pin.number] = (-x_body - 2.54, y, side)
                else:
                    self.pin_xy[pin.number] = (x_body + 2.54, y, side)

        for side in ("top", "bottom"):
            pins = groups[side]
            for index, pin in enumerate(pins):
                x = (index - (len(pins) - 1) / 2) * self.pin_pitch
                if side == "top":
                    self.pin_xy[pin.number] = (x, y_top - 2.54, side)
                else:
                    self.pin_xy[pin.number] = (x, y_bottom + 2.54, side)

    @property
    def body_height(self) -> float:
        rows = max(
            len([p for p in self.pins if p.side == "left"]),
            len([p for p in self.pins if p.side == "right"]),
            2,
        )
        return max(7.62, (rows + 1) * self.pin_pitch)


@dataclass
class Component:
    ref: str
    value: str
    kind: str
    footprint: str
    nets: dict[str, str | None]
    x: float
    y: float
    manufacturer: str = ""
    mpn: str = ""
    datasheet: str = ""
    description: str = ""
    dnp: bool = False
    in_bom: bool = True
    on_board: bool = True
    fields: dict[str, str] = field(default_factory=dict)


class Design:
    def __init__(self) -> None:
        self.symbol_types: dict[str, SymbolType] = {}
        self.components: list[Component] = []
        self.notes: list[tuple[float, float, str, float]] = []

    def symbol_type(
        self,
        name: str,
        reference: str,
        pins: Iterable[Pin],
        description: str,
        width: float = 20.32,
    ) -> None:
        item = SymbolType(name, reference, list(pins), description, width)
        item.calculate_geometry()
        self.symbol_types[name] = item

    def add(
        self,
        ref: str,
        value: str,
        kind: str,
        footprint: str,
        nets: Iterable[str | None] | dict[str, str | None],
        x: float,
        y: float,
        *,
        manufacturer: str = "",
        mpn: str = "",
        datasheet: str = "",
        description: str = "",
        dnp: bool = False,
        in_bom: bool = True,
        on_board: bool = True,
        fields: dict[str, str] | None = None,
    ) -> None:
        pins = self.symbol_types[kind].pins
        if isinstance(nets, dict):
            netmap = dict(nets)
        else:
            values = list(nets)
            if len(values) != len(pins):
                raise ValueError(f"{ref}: got {len(values)} nets for {len(pins)} pins")
            netmap = {pin.number: net for pin, net in zip(pins, values)}
        unknown = set(netmap) - {pin.number for pin in pins}
        if unknown:
            raise ValueError(f"{ref}: unknown pins {sorted(unknown)}")
        for pin in pins:
            netmap.setdefault(pin.number, None)
        # KiCad's standard connection grid is 1.27 mm.  Keeping every symbol
        # origin on that grid also keeps all generated pin endpoints on-grid.
        x = round(x / 1.27) * 1.27
        y = round(y / 1.27) * 1.27
        self.components.append(
            Component(
                ref,
                value,
                kind,
                footprint,
                netmap,
                x,
                y,
                manufacturer,
                mpn,
                datasheet,
                description or self.symbol_types[kind].description,
                dnp,
                in_bom,
                on_board,
                fields or {},
            )
        )

    def note(self, x: float, y: float, text: str, size: float = 2.0) -> None:
        self.notes.append((x, y, text, size))


def standard_symbol_types(d: Design) -> None:
    d.symbol_type(
        "R", "R", [Pin("1", "1"), Pin("2", "2", side="right")],
        "Resistor", width=5.08,
    )
    d.symbol_type(
        "C", "C", [Pin("1", "1"), Pin("2", "2", side="right")],
        "Capacitor", width=5.08,
    )
    d.symbol_type(
        "D", "D", [Pin("1", "K"), Pin("2", "A", side="right")],
        "Diode", width=5.08,
    )
    d.symbol_type(
        "D_BIDIR", "D", [Pin("1", "1"), Pin("2", "2", side="right")],
        "Bidirectional low-leakage ESD suppressor", width=5.08,
    )
    d.symbol_type(
        "L", "L", [Pin("1", "1"), Pin("2", "2", side="right")],
        "Inductor or ferrite bead", width=5.08,
    )
    d.symbol_type(
        "FUSE", "F", [Pin("1", "1"), Pin("2", "2", side="right")],
        "Resettable fuse", width=5.08,
    )
    d.symbol_type(
        "LED", "D", [Pin("1", "K"), Pin("2", "A", side="right")],
        "Low-current status LED", width=5.08,
    )
    d.symbol_type(
        "XTAL4", "Y",
        [Pin("1", "X1"), Pin("2", "GND1", side="bottom"), Pin("3", "X2", side="right"), Pin("4", "GND2", side="top")],
        "Four-pad crystal", width=7.62,
    )
    d.symbol_type(
        "XTAL2", "Y", [Pin("1", "X1"), Pin("2", "X2", side="right")],
        "Two-pad crystal", width=7.62,
    )
    d.symbol_type(
        "PMOS", "Q",
        [Pin("1", "G"), Pin("2", "S", side="right"), Pin("3", "D", side="right")],
        "P-channel MOSFET", width=7.62,
    )
    d.symbol_type(
        "ANT", "AE", [Pin("1", "FEED"), Pin("2", "NC", side="right")],
        "2.4 GHz chip antenna; terminal 2 is mechanical NC", width=7.62,
    )
    d.symbol_type(
        "TP", "TP", [Pin("1", "1")], "Test point", width=5.08,
    )
    d.symbol_type(
        "PWR_FLAG", "#FLG", [Pin("1", "pwr", "power_out")],
        "ERC power-source declaration; no physical part", width=5.08,
    )


def ic_symbol_types(d: Design) -> None:
    d.symbol_type(
        "ECG_CONN", "J",
        [Pin(str(i), name, side="right") for i, name in enumerate(("RA", "LA", "LL", "RL", "V5", "SHIELD"), 1)],
        "Molex Pico-EZmate six-position ECG harness connector", width=12.7,
    )
    d.symbol_type(
        "BAT_CONN", "J", [Pin("1", "BAT+", side="right"), Pin("2", "GND", side="right")],
        "Protected 1S LiPo connector", width=10.16,
    )
    d.symbol_type(
        "POGO4", "J",
        [Pin("1", "VBUS", side="right"), Pin("2", "D-", side="right"), Pin("3", "D+", side="right"), Pin("4", "GND", side="right")],
        "Four-contact USB pogo interface", width=12.7,
    )
    d.symbol_type(
        "SWD5", "J",
        [Pin("1", "3V0_D", side="right"), Pin("2", "GND", side="right"), Pin("3", "SWDIO", side="right"), Pin("4", "SWCLK", side="right"), Pin("5", "NRST", side="right")],
        "Five-contact hidden SWD pogo interface", width=12.7,
    )

    ads_grid = {
        "H1": ("IN1P", "input"), "G1": ("IN2P", "input"), "F1": ("IN3P", "input"), "E1": ("IN4P", "input"),
        "D1": ("IN5P", "input"), "C1": ("IN6P", "input"), "B1": ("IN7P", "input"), "A1": ("IN8P", "input"),
        "H2": ("IN1N", "input"), "G2": ("IN2N", "input"), "F2": ("IN3N", "input"), "E2": ("IN4N", "input"),
        "D2": ("IN5N", "input"), "C2": ("IN6N", "input"), "B2": ("IN7N", "input"), "A2": ("IN8N", "input"),
        "H3": ("VREFP", "bidirectional"), "G3": ("VCAP4", "passive"), "F3": ("TESTN_PACE_OUT2", "bidirectional"),
        "E3": ("TESTP_PACE_OUT1", "bidirectional"), "D3": ("WCT", "output"), "C3": ("RLDINV", "bidirectional"),
        "B3": ("RLDOUT", "output"), "A3": ("RLDIN", "input"),
        "H4": ("VREFN", "input"), "G4": ("RESP_MODP", "output"), "F4": ("RESP_MODN", "output"),
        "E4": ("RESV1", "input"), "D4": ("AVSS", "power_in"), "C4": ("RLDREF", "input"),
        "B4": ("AVDD", "power_in"), "A4": ("AVDD", "power_in"),
        "H5": ("VCAP1", "passive"), "G5": ("PWDN", "input"), "F5": ("GPIO1", "bidirectional"),
        "E5": ("GPIO4", "bidirectional"), "D5": ("AVSS", "power_in"), "C5": ("AVSS", "power_in"),
        "B5": ("AVSS", "power_in"), "A5": ("AVSS", "power_in"),
        "H6": ("VCAP2", "passive"), "G6": ("RESET", "input"), "F6": ("DAISY_IN", "input"),
        "E6": ("GPIO3", "bidirectional"), "D6": ("DRDY", "output"), "C6": ("AVDD", "power_in"),
        "B6": ("AVDD", "power_in"), "A6": ("AVDD", "power_in"),
        "H7": ("DGND", "power_in"), "G7": ("START", "input"), "F7": ("CS", "input"),
        "E7": ("GPIO2", "bidirectional"), "D7": ("DGND", "power_in"), "C7": ("DGND", "power_in"),
        "B7": ("VCAP3", "passive"), "A7": ("AVDD1", "power_in"),
        "H8": ("DIN", "input"), "G8": ("CLK", "bidirectional"), "F8": ("SCLK", "input"),
        "E8": ("DOUT", "output"), "D8": ("DVDD", "power_in"), "C8": ("DVDD", "power_in"),
        "B8": ("CLKSEL", "input"), "A8": ("AVSS1", "power_in"),
    }
    ads_pins: list[Pin] = []
    ordered_balls = [f"{col}{row}" for row in range(1, 9) for col in "HGFEDCBA"]
    for index, ball in enumerate(ordered_balls):
        name, etype = ads_grid[ball]
        ads_pins.append(Pin(ball, name, etype, "left" if index < 32 else "right"))
    d.symbol_type(
        "ADS1294R", "U", ads_pins,
        "TI four-channel 24-bit ECG AFE with RLD, WCT and respiration support", width=30.48,
    )

    stm_names = {
        1:"VBAT",2:"PC13",3:"PC14-OSC32_IN",4:"PC15-OSC32_OUT",5:"PH3-BOOT0",6:"PB8",7:"PB9",8:"NRST",
        9:"PC0",10:"PC1",11:"PC2",12:"PC3",13:"VREF+",14:"VDDA",15:"PA0",16:"PA1",17:"PA2",18:"PA3",
        19:"PA4",20:"PA5",21:"PA6",22:"PA7",23:"PA8",24:"PA9",25:"PC4",26:"PC5",27:"PB2",28:"PB10",
        29:"PB11",30:"VDD",31:"RF1",32:"VSSRF",33:"VDDRF",34:"OSC_OUT",35:"OSC_IN",36:"AT0",37:"AT1",
        38:"PB0",39:"PB1",40:"PE4",41:"VFBSMPS",42:"VSSSMPS",43:"VLXSMPS",44:"VDDSMPS",45:"VDD",
        46:"PB12",47:"PB13",48:"PB14",49:"PB15",50:"PC6",51:"PA10",52:"PA11",53:"PA12",54:"PA13",
        55:"VDDUSB",56:"PA14",57:"PA15",58:"PC10",59:"PC11",60:"PC12",61:"PD0",62:"PD1",63:"PB3",
        64:"PB4",65:"PB5",66:"PB6",67:"PB7",68:"VDD",69:"VSS_EP",
    }
    power_names = {"VBAT", "VREF+", "VDDA", "VDD", "VSSRF", "VDDRF", "VSSSMPS", "VDDSMPS", "VDDUSB", "VSS_EP"}
    output_names = {"RF1", "OSC_OUT", "VLXSMPS"}
    stm_pins = []
    for number in range(1, 70):
        name = stm_names[number]
        etype = "power_in" if name in power_names else ("output" if name in output_names else "bidirectional")
        stm_pins.append(Pin(str(number), name, etype, "left" if number <= 35 else "right"))
    d.symbol_type(
        "STM32WB55RG", "U", stm_pins,
        "ST dual-core BLE/802.15.4 MCU, 1 MB Flash, USB FS", width=35.56,
    )

    d.symbol_type(
        "BMI270", "U",
        [
            Pin("1","SDO/ADDR","input"), Pin("2","ASDx","bidirectional"), Pin("3","ASCx","bidirectional"),
            Pin("4","INT1","bidirectional"), Pin("5","VDDIO","power_in"), Pin("6","GNDIO","power_in"), Pin("7","GND","power_in"),
            Pin("8","VDD","power_in","right"), Pin("9","INT2","bidirectional","right"), Pin("10","OCSB","input","right"),
            Pin("11","OSDO","output","right"), Pin("12","CSB","input","right"), Pin("13","SCx/SCL","input","right"),
            Pin("14","SDx/SDA","bidirectional","right"),
        ],
        "Bosch six-axis low-power IMU", width=20.32,
    )
    d.symbol_type(
        "TPS2116", "U",
        [Pin("1","GND","power_in"),Pin("2","VOUT","power_out"),Pin("3","VIN1","power_in"),Pin("4","PR1","input"),
         Pin("5","MODE","input","right"),Pin("6","VIN2","power_in","right"),Pin("7","VOUT","passive","right"),Pin("8","ST","open_collector","right")],
        "TI low-IQ two-input power mux with reverse-current blocking", width=17.78,
    )
    d.symbol_type(
        "LDO5", "U",
        [Pin("1","IN","power_in"),Pin("2","GND","power_in"),Pin("3","EN","input"),Pin("4","NC","no_connect","right"),Pin("5","OUT","power_out","right")],
        "Fixed-output low-noise LDO in SOT-23-5", width=15.24,
    )
    d.symbol_type(
        "LOADSW6", "U",
        [Pin("1","VIN","power_in"),Pin("2","GND","power_in"),Pin("3","CT","passive"),Pin("4","ON","input","right"),Pin("5","QOD","passive","right"),Pin("6","VOUT","power_out","right")],
        "TI controlled-rise-time load switch", width=15.24,
    )
    d.symbol_type(
        "USB_ESD", "U",
        [Pin("1","D+"),Pin("2","GND","power_in"),Pin("3","D-",side="right")],
        "Two-channel low-capacitance USB ESD protection", width=10.16,
    )
    d.symbol_type(
        "MLPF", "U",
        [Pin("A1","OUT"),Pin("A2","GND","power_in"),Pin("A3","IN","input"),Pin("B1","GND","power_in","right"),Pin("B2","GND","power_in","right"),Pin("B3","GND","power_in","right")],
        "ST integrated matching and low-pass filter for STM32WB55Cx/Rx", width=12.7,
    )
    sd_pins = [
        Pin("1","DAT2"),Pin("2","DAT3/CS"),Pin("3","CMD/DI"),Pin("4","VDD","power_in"),Pin("5","CLK","input"),
        Pin("6","VSS","power_in","right"),Pin("7","DAT0/DO","output","right"),Pin("8","DAT1",side="right"),
        Pin("9","DET_A",side="right"),Pin("10","DET_B",side="right"),Pin("SH","SHIELD","power_in","bottom"),
    ]
    d.symbol_type(
        "MICROSD", "J", sd_pins,
        "Molex 104031-0811 microSD push-pull connector with card detect", width=22.86,
    )


def footprint_for(kind: str) -> str:
    table = {
        "R": "Resistor_SMD:R_0402_1005Metric",
        "C": "Capacitor_SMD:C_0402_1005Metric",
        "D": "Diode_SMD:D_SOD-323",
        "D_BIDIR": "Diode_SMD:D_SOD-882",
        "L": "Inductor_SMD:L_0603_1608Metric",
        "FUSE": "Fuse:Fuse_0603_1608Metric",
        "LED": "LED_SMD:LED_0603_1608Metric",
        "XTAL4": "Crystal:Crystal_SMD_2016-4Pin_2.0x1.6mm",
        "PMOS": "Package_TO_SOT_SMD:SOT-23",
        "ANT": "RF_Antenna:Johanson_2450AT18x100_2400-2500Mhz",
        "TP": "TestPoint:TestPoint_Pad_D1.0mm",
    }
    return table[kind]


MURATA_CAP_MPN = {
    ("100n X7R", "Capacitor_SMD:C_0402_1005Metric"): "GRM155R71C104KA88D",
    ("1n X7R", "Capacitor_SMD:C_0402_1005Metric"): "GRM155R71H102KA01D",
    ("10p C0G", "Capacitor_SMD:C_0402_1005Metric"): "GRM1555C1H100JA01D",
    ("1u X7R", "Capacitor_SMD:C_0603_1608Metric"): "GRM188R71C105KA12D",
    ("4.7u X7R", "Capacitor_SMD:C_0603_1608Metric"): "GRM188Z71A475KE15D",
    ("10u 6.3V X5R", "Capacitor_SMD:C_0603_1608Metric"): "GRM188R60J106ME47D",
    ("22u 6.3V X5R", "Capacitor_SMD:C_0603_1608Metric"): "GRM188R60J226MEA0D",
    ("22u 6.3V X5R", "Capacitor_SMD:C_0805_2012Metric"): "GRM21BR60J226ME39L",
}


def add_two(
    d: Design,
    ref: str,
    value: str,
    kind: str,
    net1: str,
    net2: str,
    x: float,
    y: float,
    *,
    footprint: str | None = None,
    manufacturer: str = "",
    mpn: str = "",
    dnp: bool = False,
    description: str = "",
) -> None:
    resolved_footprint = footprint or footprint_for(kind)
    if manufacturer == "Murata" and not mpn:
        mpn = MURATA_CAP_MPN.get((value, resolved_footprint), "")
    d.add(
        ref, value, kind, resolved_footprint, [net1, net2], x, y,
        manufacturer=manufacturer, mpn=mpn, dnp=dnp, description=description,
    )
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

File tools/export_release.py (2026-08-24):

#!/usr/bin/env python3
"""Run KiCad sign-off checks and export review/manufacturing deliverables."""

from __future__ import annotations

import csv
import os
import re
import shutil
import subprocess
import zipfile
from dataclasses import dataclass
from pathlib import Path


ROOT = Path(__file__).resolve().parents[1]
PDF = ROOT / "pdf"
DOCS = ROOT / "docs"
PRODUCTION = ROOT / "production"


@dataclass(frozen=True)
class Target:
    slug: str
    directory: Path
    stem: str
    copper: tuple[str, ...]
    bom_source: Path

    @property
    def schematic(self) -> Path:
        return self.directory / f"{self.stem}.kicad_sch"

    @property
    def board(self) -> Path:
        return self.directory / f"{self.stem}.kicad_pcb"


TARGETS = (
    Target(
        "main_board",
        ROOT / "hardware" / "holter_v1",
        "holter_v1",
        ("F.Cu", "In1.Cu", "In2.Cu", "B.Cu"),
        DOCS / "bom_source.csv",
    ),
    Target(
        "usb_pogo_dock",
        ROOT / "hardware" / "usb_pogo_dock",
        "usb_pogo_dock",
        ("F.Cu", "B.Cu"),
        DOCS / "dock_bom_source.csv",
    ),
)


def natural_key(text: str) -> tuple[object, ...]:
    return tuple(int(part) if part.isdigit() else part for part in re.split(r"(\d+)", text))


def find_kicad_cli() -> str:
    configured = os.environ.get("KICAD_CLI")
    if configured:
        path = Path(configured).expanduser().resolve()
        if path.is_file():
            return str(path)
        raise SystemExit(f"KICAD_CLI does not point to a file: {path}")
    found = shutil.which("kicad-cli")
    if found:
        return found
    raise SystemExit("kicad-cli was not found; install KiCad 10 or set KICAD_CLI")


KICAD = find_kicad_cli()


def run(*args: object) -> None:
    command = [str(item) for item in args]
    print("+", " ".join(command))
    subprocess.run(command, cwd=ROOT, check=True)


def assert_signoff_report(path: Path, *, schematic: bool) -> None:
    report = path.read_text(encoding="utf-8")
    if schematic:
        expected = "ERC messages: 0  Errors 0  Warnings 0"
        if expected not in report:
            raise SystemExit(f"ERC is not clean: {path.relative_to(ROOT)}")
        return
    required = ("Found 0 DRC violations", "Found 0 unconnected pads", "Found 0 Footprint errors")
    missing = [text for text in required if text not in report]
    if missing:
        raise SystemExit(f"PCB sign-off is not clean ({', '.join(missing)}): {path.relative_to(ROOT)}")


def write_grouped_bom(target: Target, output: Path) -> None:
    rows = list(csv.DictReader(target.bom_source.open(encoding="utf-8-sig")))
    fitted = [row for row in rows if not row["DNP"]]
    missing = [
        row["Reference"]
        for row in fitted
        if not row["Manufacturer Part Number"]
    ]
    if missing:
        raise SystemExit(f"Fitted BOM rows without an MPN in {target.bom_source.name}: {', '.join(missing)}")

    groups: dict[tuple[str, str, str, str], list[str]] = {}
    for row in fitted:
        key = (
            row["Value"],
            row["Footprint"].split(":")[-1],
            row["Manufacturer"],
            row["Manufacturer Part Number"],
        )
        groups.setdefault(key, []).append(row["Reference"])

    with output.open("w", newline="", encoding="utf-8-sig") as handle:
        writer = csv.writer(handle, lineterminator="\n")
        writer.writerow(
            [
                "Comment",
                "Designator",
                "Footprint",
                "LCSC Part #",
                "Manufacturer Part Number",
                "Manufacturer",
                "Quantity",
            ]
        )
        for key, references in sorted(groups.items(), key=lambda item: natural_key(min(item[1], key=natural_key))):
            value, footprint, manufacturer, mpn = key
            references.sort(key=natural_key)
            writer.writerow([value, ",".join(references), footprint, "", mpn, manufacturer, len(references)])


def fitted_references(target: Target) -> set[str]:
    with target.bom_source.open(encoding="utf-8-sig", newline="") as handle:
        rows = list(csv.DictReader(handle))
    return {row["Reference"] for row in rows if not row["DNP"]}


def transform_position_file(source: Path, output: Path, allowed_references: set[str]) -> None:
    with source.open(newline="", encoding="utf-8-sig") as handle:
        rows = [
            row
            for row in csv.DictReader(handle)
            if row["Ref"] in allowed_references
        ]
    with output.open("w", newline="", encoding="utf-8-sig") as handle:
        writer = csv.writer(handle, lineterminator="\n")
        writer.writerow(["Designator", "Mid X", "Mid Y", "Layer", "Rotation"])
        for row in sorted(rows, key=lambda item: natural_key(item["Ref"])):
            layer = "Top" if row["Side"].lower() == "top" else "Bottom"
            # KiCad's CSV uses a Cartesian Y axis, so board locations below
            # the top-left origin are negative.  JLC-style CPL files expect
            # positive board coordinates.  Normalize rotations at the same
            # time so no assembler has to interpret negative angles.
            pos_y = -float(row["PosY"])
            rotation = float(row["Rot"]) % 360.0
            writer.writerow(
                [
                    row["Ref"],
                    f"{float(row['PosX']):.6f}mm",
                    f"{pos_y:.6f}mm",
                    layer,
                    f"{rotation:.6f}",
                ]
            )


def zip_fabrication_files(source_dir: Path, output: Path) -> None:
    with zipfile.ZipFile(output, "w", compression=zipfile.ZIP_DEFLATED, compresslevel=9) as archive:
        for path in sorted(source_dir.iterdir()):
            if path.is_file() and path != output:
                archive.write(path, path.name)
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

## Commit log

2026-08-24 Release Holter V1 hardware design
    [bom_source.csv, dock_bom_source.csv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]
2026-08-24 refactor: archive V1 and add clean PCB rebuild workflow
    [bom_source.csv, dock_bom_source.csv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]
2026-08-26 5.6sol update v2
    [bat_trial_tracks_only.kicad_pcb, gpio_bank_v2_tracks_only.kicad_pcb, gpio_probe_tracks_only.kicad_pcb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]
